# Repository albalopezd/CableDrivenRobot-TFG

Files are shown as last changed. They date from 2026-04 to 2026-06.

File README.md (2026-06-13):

# Robot continuo accionado por cables (2 GDL) — TFG

Trabajo de Fin de Grado. Diseño, construcción y control de un **robot continuo accionado por
cables** (*cable-driven continuum robot*) de 4 segmentos, accionado por 3 tendones, con
2 grados de libertad que posicionan el extremo en el plano XY. El robot se
modela con **cinemática de curvatura constante por tramos (PCC)** y se controla en tiempo real
con **ROS2 Jazzy + ros2_control**, un **Arduino** como intermediario y tres **servos LX-16A**.
Incluye cinemática directa e inversa, visualización en RViz, interfaz gráfica y validación
experimental sobre el robot físico.

<p align="center">
  
  
  WhatsApp Image
</p>

---

## 🎬 Vídeos

| Primera aproximación de movimiento | Demostración IK | Demostración sliders
|:---:|:---:|:---:|
| Primera aproximación de movimiento (https://www.youtube.com/shorts/9lynUKzb-aw) | Demo IK (https://youtu.be/HkvytLLgjOQ) | Demo sliders (https://youtu.be/xODviwTWwIY) |
| Pruebas iniciales de actuación de los cables y respuesta del robot. | Funcionamiento completo: control cinemático. | Funcionamiento por variación longitud de cables manual |

---

## Descripción del proyecto

Un robot continuo no tiene articulaciones rígidas: su estructura se deforma de forma continua.
En este caso, una columna central flexible recorre **4 segmentos** separados por discos, y
**3 cables (tendones)** dispuestos a **0°, +90° y −90°** (triángulo isósceles rectángulo) tiran
de los segmentos para curvar el robot en cualquier dirección del plano.

Al ser una **única sección de curvatura constante**, el robot tiene **2 grados de libertad**:
la **curvatura** (cuánto dobla) y la **orientación del plano de doblez** (hacia dónde dobla).
Esos 2 GDL posicionan el extremo en el plano **XY**. Los 3 tendones son redundantes respecto a
esos 2 GDL: aportan tensión y equilibrio, no una dirección de movimiento adicional. La
coordenada **z no es un grado de libertad independiente**, sino una consecuencia geométrica del
doblez (el extremo se acorta en vertical al curvarse).

El comportamiento se describe con el modelo **PCC (Piecewise Constant Curvature)**, que asume
curvatura constante en cada tramo y permite resolver:

- **Cinemática inversa (IK):** dada una posición objetivo del extremo `(x, y, z)`, calcula
  cuánto debe tirar cada cable.
- **Cinemática directa (FK):** dada la longitud de cada cable, estima la posición del extremo.

### Parámetros del robot

| Parámetro | Valor |
|---|---|
| Número de segmentos | 4 |
| Grados de libertad | 2 (curvatura + orientación del plano de doblez) |
| Separación entre discos | 0,053 m |
| Número de cables (tendones) | 3, a 0°, +90° y −90° (triángulo isósceles rectángulo) |
| Servos | LX-16A — IDs 7, 10 y 4 |

---

## Hardware

**Componentes principales:**

- 3× servos **LX-16A** (Lewansoul) en bus serie semidúplex, cada uno acciona un tendón.
- **Arduino** como pasarela entre el PC y el bus de servos.
- Fuente externa **6 V** (LiPo 2S) para alimentar los servos, con masa común con el Arduino.
- Piezas estructurales impresas en **PLA** (FDM): segmentos separadores, base, poleas de
  tendones y soportes.

**Arquitectura de comunicación (dos capas):**

```
PC  ──USB, 9600 baud──►  Arduino  ──SoftwareSerial, 115200 baud──►  Bus LX-16A (3 servos)
```

El Arduino recibe comandos del PC por el puerto USB (Hardware Serial) y los traduce al protocolo
del bus Lewansoul (SoftwareSerial), además de devolver lecturas de voltaje de los servos.

**Recursos de diseño en el repositorio:**

- [`schematics/`](schematics/) — esquema eléctrico (KiCad).
- [`parts/`](parts/) — piezas mecánicas (FreeCAD, `.FCStd`).
- [`meshes/`](meshes/) — mallas `.STL` para impresión y visualización en RViz.

---

## Arquitectura software (ROS2)

El control se reparte en cuatro paquetes ROS2 dentro de [`ros2_ws/src/`](ros2_ws/src/):

| Paquete | Función |
|---|---|
| `cable_robot_kinematics` | Cinemática PCC (IK/FK) y nodos puente, GUI e interfaz de control. |
| `cable_robot_description` | Modelo URDF (xacro), mallas y configuración de RViz. |
| `cable_robot_hardware` | Plugin de `ros2_control` (`SystemInterface`) que comunica por puerto serie con el Arduino. |
| `cable_robot_bringup` | Fichero de *launch* y configuración de controladores. |

**Nodos principales** (`cable_robot_kinematics`):

- `ik_bridge_cpp` — cinemática inversa: `desired_pose` → comandos de cable.
- `fk_bridge_cpp` — cinemática directa: estado de los cables → `estimated_pose`.
- `cable_bend_bridge_cpp` / `joint_state_combiner_cpp` — convierten el estado de los cables a
  curvatura por segmento para visualizar la deformación en RViz.
- `hardware_controller.py` — control proporcional de velocidad sobre los servos.
- `cable_slider_gui.py` — interfaz Tkinter para mover cada cable y enviar objetivos de IK.
- `data_logger.py` — registro de datos a CSV.

**Flujo de control:**

```
            ┌──────────────┐   cables   ┌────────────┐  serie  ┌─────────┐   ┌─────────┐
desired_pose│  ik_bridge   ├───────────►│ ros2_control├────────►│ Arduino ├──►│ LX-16A  │
   (RViz/   │   (IK PCC)   │            │  + plugin   │         │         │   │ (×3)    │
    GUI)    └──────────────┘            └─────┬───────┘         └─────────┘   └─────────┘
                                              │ /joint_states
                                        ┌─────▼───────┐
                                        │  fk_bridge  │──► estimated_pose ──► RViz / GUI
                                        │   (FK PCC)  │
                                        └─────────────┘
```

**Firmware Arduino** en [`Arduino/main/`](Arduino/main/): sketch principal (`main.ino`) más las
librerías `LX16A`, `TendonRobot` y `PCCkinematics` (que permiten también un modo de control
autónomo sin ROS).

---

## Requisitos

- **Ubuntu** con **ROS2 Jazzy**.
- `ros2_control` y `ros2_controllers` (`sudo apt install ros-jazzy-ros2-control ros-jazzy-ros2-controllers`).
- `xacro` y `colcon`.
- **Arduino IDE** para cargar el firmware.
- *Opcional:* PlotJuggler (`sudo apt install ros-jazzy-plotjuggler-ros`) para visualizar
  señales en tiempo real.

---

## Instalación y compilación

```bash
git clone https://github.com/albalopezd/CableDrivenRobot-TFG.git
cd CableDrivenRobot-TFG/ros2_ws
colcon build
source install/setup.bash
```

Carga el firmware en el Arduino abriendo `Arduino/main/main.ino` en el Arduino IDE y subiéndolo
a la placa.

---

## Ejecución

Con el robot conectado por USB:

```bash
source /opt/ros/jazzy/setup.bash
source ~/CableDrivenRobot-TFG/ros2_ws/install/setup.bash
ros2 launch cable_robot_bringup bringup.launch.py
```

Esto arranca toda la arquitectura con un solo comando: `ros2_control`, `robot_state_publisher`,
**RViz**, los controladores, los puentes de cinemática (IK/FK) y la **GUI** de control.

El puerto serie se puede ajustar con el argumento `serial_port` (por defecto `/dev/ttyACM0`):

```bash
ros2 launch cable_robot_bringup bringup.launch.py serial_port:=/dev/ttyACM1
```

---

## Resultados y validación

Se grabaron tres pruebas experimentales sobre el robot físico (rosbags en
[`ros2_ws/bags/`](ros2_ws/bags/)):

1. **Sliders manuales** — actuación independiente de cada cable.
2. **Control por cinemática inversa** — seguimiento de una secuencia de *waypoints* en el plano XY.
3. **Evaluación de la cinemática directa** — comparación entre posición estimada y deseada.

**Error de posicionamiento en estado estacionario (plano XY):**

| Tipo de objetivo | Error XY |
|---|---|
| Ejes simples (X o Y) | ≈ 0,8 – 1,2 mm |
| Diagonales | ≈ 7 mm |

Los rosbags de las tres pruebas están disponibles en [`ros2_ws/bags/`](ros2_ws/bags/) para
su reproducción y análisis.

---

## Estructura del repositorio

```
CableDrivenRobot-TFG/
├── Arduino/      Firmware del Arduino (sketch + librerías LX16A, TendonRobot, PCCkinematics)
├── ros2_ws/      Workspace ROS2 (4 paquetes) + rosbags
├── parts/        Piezas mecánicas en FreeCAD (.FCStd)
├── meshes/       Mallas .STL para impresión 3D y RViz
├── schematics/   Esquema eléctrico (KiCad)
├── scenes/       Escenas de CoppeliaSim (validación cinemática previa)
└── csv/          Datos de validación cinemática (simulación)
```

---

## Validación previa en CoppeliaSim

Antes de la implementación física, la cinemática se validó en simulación con **CoppeliaSim**.
Las escenas están en [`scenes/`](scenes/) (`kinematic_3d_validation.ttt`,
`kinematic_3d_validation_complete_arm.ttt`) y los datos generados en [`csv/`](csv/), comparando
posición real (simulada) frente a la teórica para cinemática directa e inversa.

---

## Autoría

Trabajo de Fin de Grado — Alba López.

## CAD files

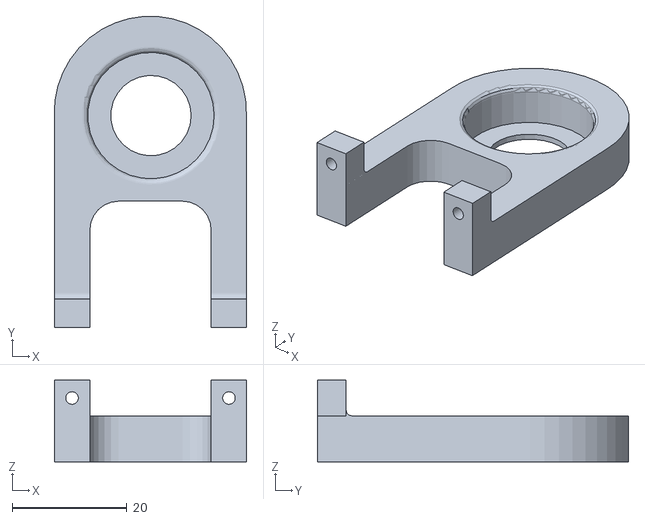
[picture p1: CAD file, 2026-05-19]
meshes/holder.stl
33.5 x 54.2 x 14.2

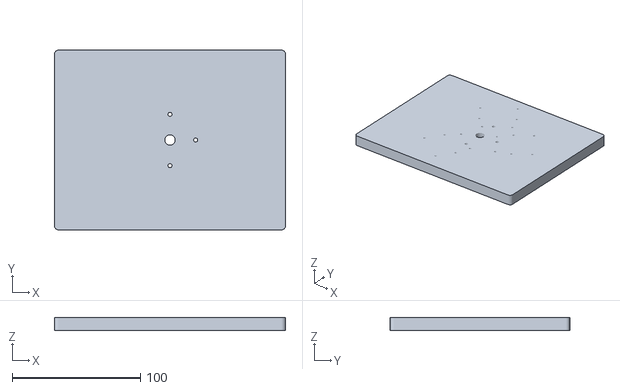
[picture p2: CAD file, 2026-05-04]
ros2_ws/src/cable_robot_description/meshes/base.stl
180.0 x 140.0 x 10.0

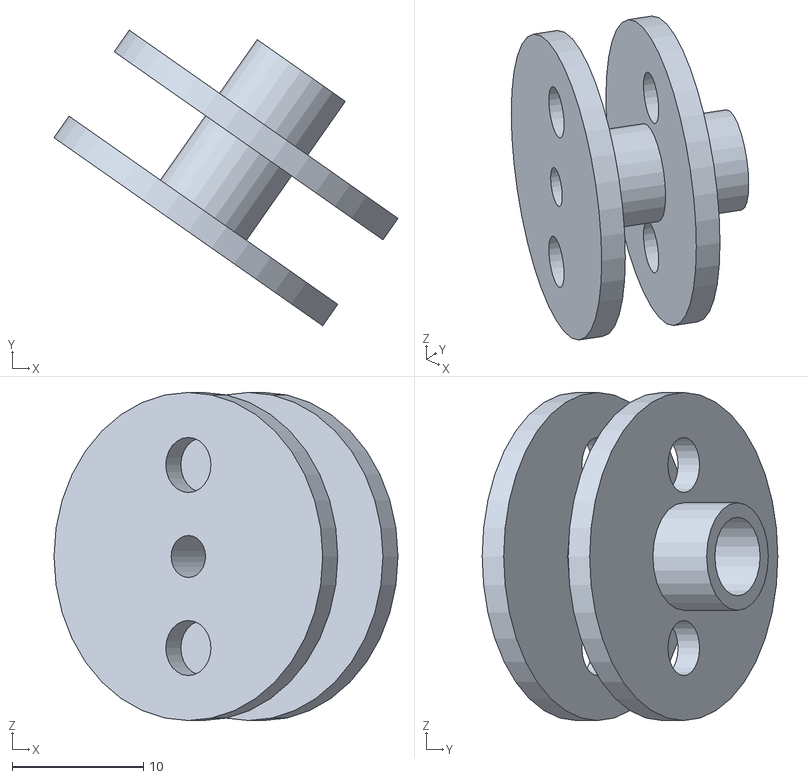
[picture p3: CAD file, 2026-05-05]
meshes/pulley.stl
26.2 x 22.5 x 25.0

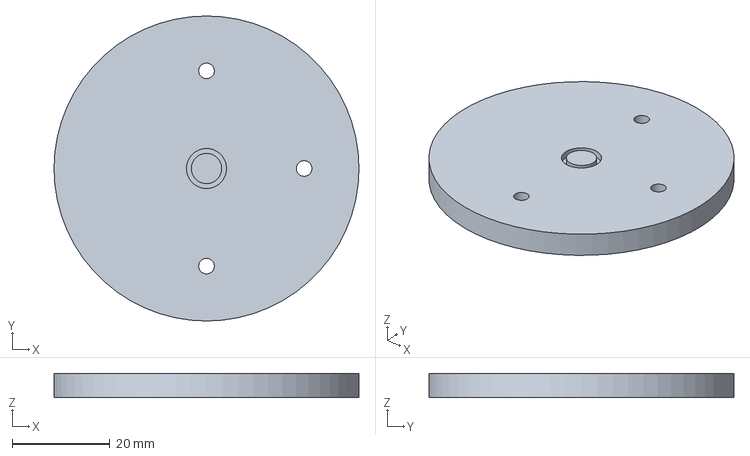
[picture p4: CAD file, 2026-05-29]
parts/segment.FCStd
62.5 x 62.5 x 5.00 mm

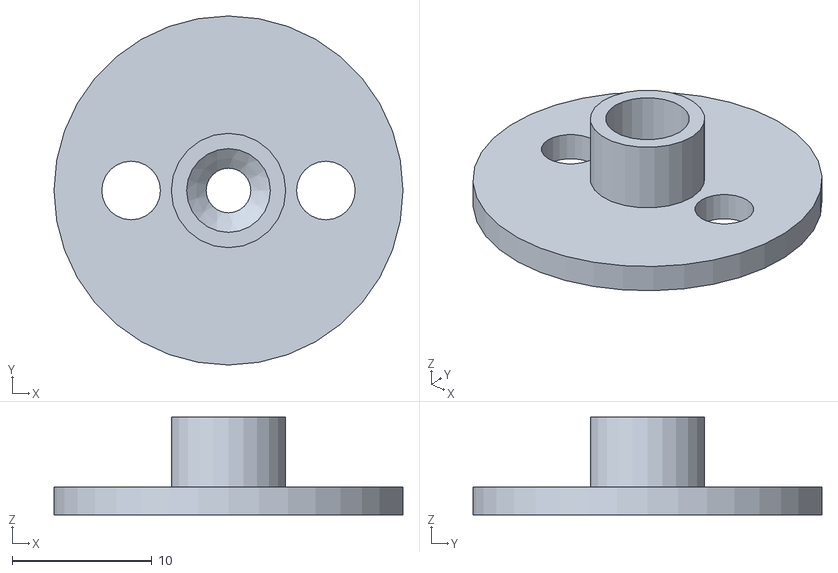
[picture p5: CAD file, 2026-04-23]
ros2_ws/src/cable_robot_description/meshes/pulley_up.stl
25.0 x 25.0 x 7.00

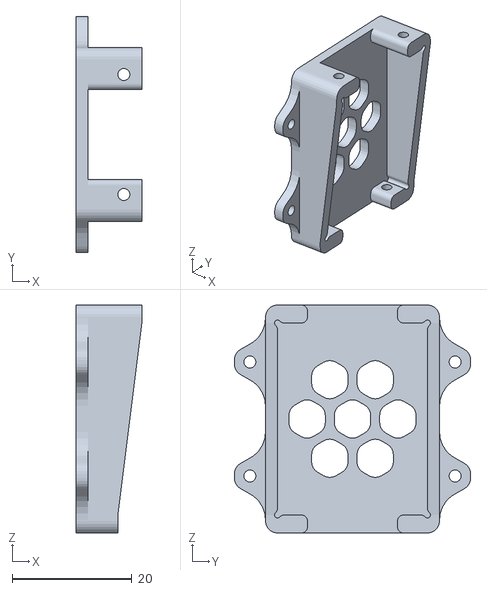
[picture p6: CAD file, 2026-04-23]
ros2_ws/src/cable_robot_description/meshes/servo_bottom_mount.stl
11.0 x 39.4 x 38.0

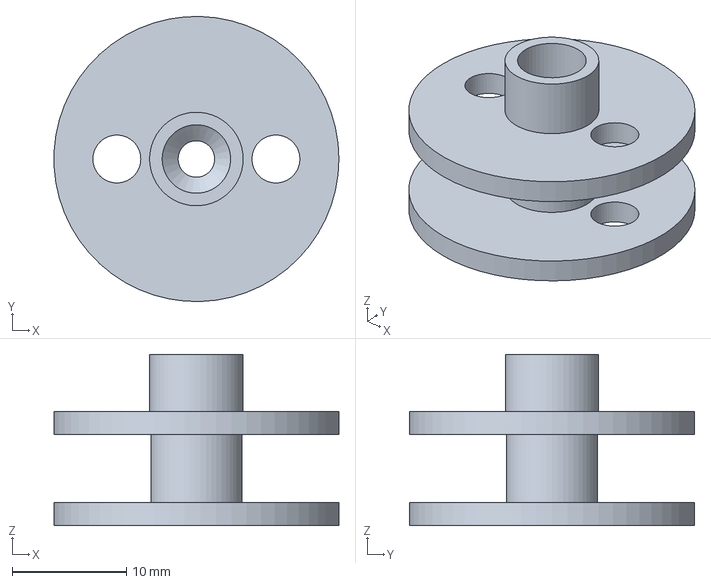
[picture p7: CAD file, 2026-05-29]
parts/pulley.FCStd
25.0 x 25.0 x 15.0 mm

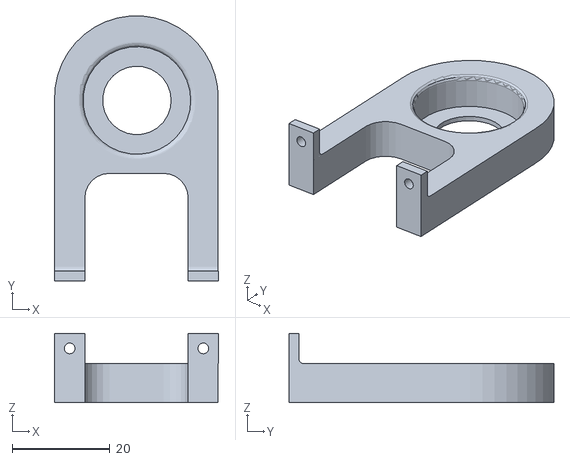
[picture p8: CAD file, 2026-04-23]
ros2_ws/src/cable_robot_description/meshes/holder.stl
33.5 x 54.2 x 14.2

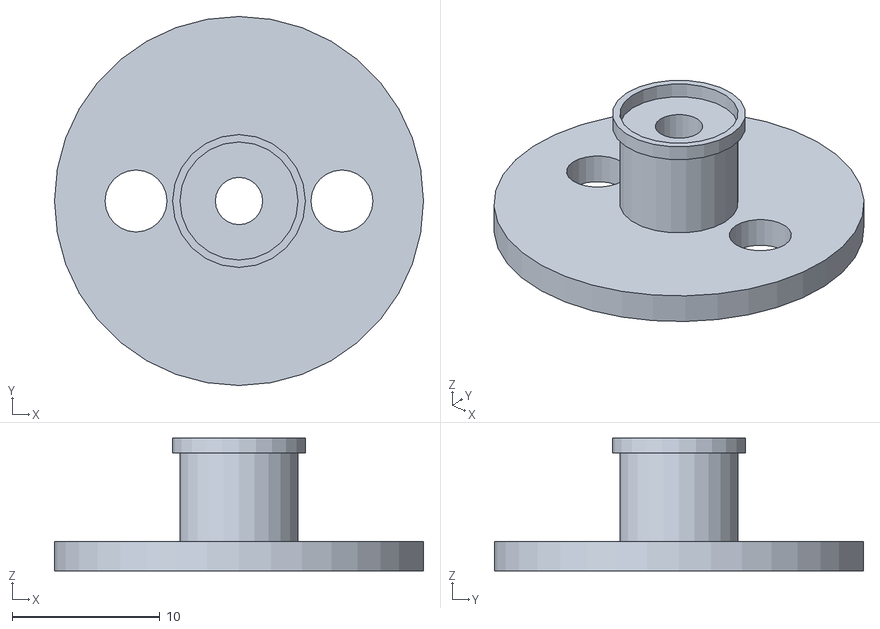
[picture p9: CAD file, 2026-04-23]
ros2_ws/src/cable_robot_description/meshes/pulley_down.stl
25.0 x 25.0 x 9.00

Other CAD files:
parts/holder.FCStd
parts/base.FCStd
ros2_ws/src/cable_robot_description/meshes/segment.stl

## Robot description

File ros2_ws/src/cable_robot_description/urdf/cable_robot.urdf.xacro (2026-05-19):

<?xml version="1.0"?>
<robot name="cable_robot" xmlns:xacro="http://www.ros.org/wiki/xacro">

  <xacro:property name="mesh_dir" value="package://cable_robot_description/meshes"/>
  <xacro:property name="mesh_scale" value="0.001"/>
  <xacro:property name="segment_spacing" value="0.05675"/>
  <xacro:property name="cable_radius_offset" value="0.02"/>
  <xacro:property name="cable_radius" value="0.0012"/>
  <xacro:property name="cable_length" value="0.240"/>
  <xacro:property name="cable_start_z" value="-0.01"/>
  <xacro:property name="cable_travel" value="0.08"/>
  <xacro:property name="base_cable_section_length" value="${segment_spacing - cable_start_z}"/>
  <xacro:property name="deg_to_rad" value="0.017453292519943295"/>
  <xacro:property name="cable_1_angle_deg" value="90.0"/>
  <xacro:property name="cable_2_angle_deg" value="-90.0"/>
  <xacro:property name="cable_3_angle_deg" value="0"/>
  <xacro:property name="cable_1_angle" value="${cable_1_angle_deg * deg_to_rad}"/>
  <xacro:property name="cable_2_angle" value="${cable_2_angle_deg * deg_to_rad}"/>
  <xacro:property name="cable_3_angle" value="${cable_3_angle_deg * deg_to_rad}"/>

  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

  <xacro:macro name="segment_stage" params="segment_name parent bend_x_joint bend_y_joint z">
    <link name="${segment_name}_bend_x_link"/>

    <joint name="${bend_x_joint}" type="revolute">
      <parent link="${parent}"/>
      <child link="${segment_name}_bend_x_link"/>
      <origin xyz="0 0 0" rpy="0 0 0"/>
      <axis xyz="1 0 0"/>
      <limit lower="-1.57" upper="1.57" effort="20.0" velocity="1.0"/>
    </joint>

    <link name="${segment_name}_bend_y_link"/>

    <joint name="${bend_y_joint}" type="revolute">
      <parent link="${segment_name}_bend_x_link"/>
      <child link="${segment_name}_bend_y_link"/>
      <origin xyz="0 0 0" rpy="0 0 0"/>
      <axis xyz="0 1 0"/>
      <limit lower="-1.57" upper="1.57" effort="20.0" velocity="1.0"/>
    </joint>

    <link name="${segment_name}">
      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
    </link>

    <joint name="${segment_name}_placement_joint" type="fixed">
      <parent link="${segment_name}_bend_y_link"/>
      <child link="${segment_name}"/>
      <origin xyz="0 0 ${z}" rpy="0 0 0"/>
    </joint>
  </xacro:macro>

  <xacro:macro name="cable_link" params="name joint_name angle">
    <link name="${name}_anchor_link"/>

    <joint name="${joint_name}" type="prismatic">
      <parent link="${name}_anchor_link"/>
      <child link="${name}"/>
      <origin xyz="0 0 0" rpy="0 0 0"/>
      <axis xyz="0 0 1"/>
      <limit lower="0.0" upper="${cable_travel}" effort="50.0" velocity="0.1"/>
    </joint>

    <link name="${name}">
    </link>

    <joint name="base_to_${name}_anchor" type="fixed">
      <parent link="base_link"/>
      <child link="${name}_anchor_link"/>
      <origin xyz="${cable_radius_offset * cos(angle)} ${cable_radius_offset * sin(angle)} ${cable_start_z}" rpy="0 0 0"/>
    </joint>
  </xacro:macro>

  <xacro:macro name="cable_section" params="name parent angle z_mid length">
    <link name="${name}">
      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
    </link>

    <joint name="${parent}_to_${name}" type="fixed">
      <parent link="${parent}"/>
      <child link="${name}"/>
      <origin xyz="${cable_radius_offset * cos(angle)} ${cable_radius_offset * sin(angle)} 0" rpy="0 0 0"/>
    </joint>
  </xacro:macro>

  <link name="world"/>

  <link name="base_link">
    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
  </link>

  <joint name="world_to_base" type="fixed">
    <parent link="world"/>
    <child link="base_link"/>
  </joint>

  <xacro:segment_stage segment_name="segment_1_link" parent="base_link" bend_x_joint="joint_bend_x" bend_y_joint="joint_bend_y" z="${segment_spacing}"/>
  <xacro:segment_stage segment_name="segment_2_link" parent="segment_1_link" bend_x_joint="joint_bend_x_1" bend_y_joint="joint_bend_y_1" z="${segment_spacing}"/>
  <xacro:segment_stage segment_name="segment_3_link" parent="segment_2_link" bend_x_joint="joint_bend_x_2" bend_y_joint="joint_bend_y_2" z="${segment_spacing}"/>
  <xacro:segment_stage segment_name="segment_4_link" parent="segment_3_link" bend_x_joint="joint_bend_x_3" bend_y_joint="joint_bend_y_3" z="${segment_spacing}"/>

  <xacro:cable_link name="cable_1_link" joint_name="cable_1_joint" angle="${cable_1_angle}"/>
  <xacro:cable_section name="cable_1_base_section" parent="base_link" angle="${cable_1_angle}" z_mid="${(cable_start_z + segment_spacing) / 2.0}" length="${base_cable_section_length}"/>
  <xacro:cable_section name="cable_1_section_1" parent="segment_1_link" angle="${cable_1_angle}" z_mid="${segment_spacing / 2.0}" length="${segment_spacing}"/>
  <xacro:cable_section name="cable_1_section_2" parent="segment_2_link" angle="${cable_1_angle}" z_mid="${segment_spacing / 2.0}" length="${segment_spacing}"/>
  <xacro:cable_section name="cable_1_section_3" parent="segment_3_link" angle="${cable_1_angle}" z_mid="${segment_spacing / 2.0}" length="${segment_spacing}"/>
  <xacro:cable_link name="cable_2_link" joint_name="cable_2_joint" angle="${cable_2_angle}"/>
  <xacro:cable_section name="cable_2_base_section" parent="base_link" angle="${cable_2_angle}" z_mid="${(cable_start_z + segment_spacing) / 2.0}" length="${base_cable_section_length}"/>
  <xacro:cable_section name="cable_2_section_1" parent="segment_1_link" angle="${cable_2_angle}" z_mid="${segment_spacing / 2.0}" length="${segment_spacing}"/>
  <xacro:cable_section name="cable_2_section_2" parent="segment_2_link" angle="${cable_2_angle}" z_mid="${segment_spacing / 2.0}" length="${segment_spacing}"/>
  <xacro:cable_section name="cable_2_section_3" parent="segment_3_link" angle="${cable_2_angle}" z_mid="${segment_spacing / 2.0}" length="${segment_spacing}"/>
  <xacro:cable_link name="cable_3_link" joint_name="cable_3_joint" angle="${cable_3_angle}"/>
  <xacro:cable_section name="cable_3_base_section" parent="base_link" angle="${cable_3_angle}" z_mid="${(cable_start_z + segment_spacing) / 2.0}" length="${base_cable_section_length}"/>
  <xacro:cable_section name="cable_3_section_1" parent="segment_1_link" angle="${cable_3_angle}" z_mid="${segment_spacing / 2.0}" length="${segment_spacing}"/>
  <xacro:cable_section name="cable_3_section_2" parent="segment_2_link" angle="${cable_3_angle}" z_mid="${segment_spacing / 2.0}" length="${segment_spacing}"/>
  <xacro:cable_section name="cable_3_section_3" parent="segment_3_link" angle="${cable_3_angle}" z_mid="${segment_spacing / 2.0}" length="${segment_spacing}"/>

  <ros2_control name="CableRobotHardware" type="system">
    <hardware>
      <plugin>cable_robot_hardware/CableRobotHardware</plugin>
      <param name="port">/dev/ttyACM0</param>
      <param name="baud">9600</param>
      <param name="cable_speed">0.026</param>
    </hardware>

    <joint name="cable_1_joint">
      <command_interface name="velocity"/>
      <state_interface name="position">
        <param name="initial_value">0.0</param>
      </state_interface>
    </joint>

    <joint name="cable_2_joint">
      <command_interface name="velocity"/>
      <state_interface name="position">
        <param name="initial_value">0.0</param>
      </state_interface>
    </joint>

    <joint name="cable_3_joint">
      <command_interface name="velocity"/>
      <state_interface name="position">
        <param name="initial_value">0.0</param>
      </state_interface>
    </joint>
  </ros2_control>
</robot>

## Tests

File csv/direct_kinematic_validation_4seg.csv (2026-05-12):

time | x_real | y_real | z_real | x_theo | y_theo | z_theo | theta_total | error_dist | rho_real | bx | by | b1x | b1y | b2x | b2y | b3x | b3y
0.000000 | -0.000000 | -0.000000 | 0.307363 | 0.000000 | 0.000000 | 0.307388 | 0.000000 | 0.000025 | 0.000000 | 0.000000 | 0.000000 | 0.000000 | 0.000000 | 0.000000 | 0.000000 | 0.000000 | 0.000000
0.050000 | 0.000019 | -0.000019 | 0.307363 | 0.000019 | -0.000019 | 0.307388 | 0.000179 | 0.000025 | 0.000028 | 0.000032 | 0.000032 | 0.000032 | 0.000032 | 0.000032 | 0.000032 | 0.000032 | 0.000032
0.100000 | 0.000078 | -0.000078 | 0.307363 | 0.000078 | -0.000078 | 0.307388 | 0.000714 | 0.000025 | 0.000110 | 0.000126 | 0.000126 | 0.000126 | 0.000126 | 0.000126 | 0.000126 | 0.000126 | 0.000126
0.150000 | 0.000174 | -0.000174 | 0.307363 | 0.000174 | -0.000174 | 0.307388 | 0.001600 | 0.000025 | 0.000246 | 0.000283 | 0.000283 | 0.000283 | 0.000283 | 0.000283 | 0.000283 | 0.000283 | 0.000283
0.200000 | 0.000308 | -0.000308 | 0.307363 | 0.000308 | -0.000308 | 0.307388 | 0.002833 | 0.000025 | 0.000435 | 0.000501 | 0.000501 | 0.000501 | 0.000501 | 0.000501 | 0.000501 | 0.000501 | 0.000501
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

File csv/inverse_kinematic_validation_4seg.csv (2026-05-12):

time | target_x | target_y | target_z | real_x | real_y | real_z | error_dist | theta | phi | dl1 | dl2 | dl3 | l1 | l2 | l3
0.000000 | 0.136600 | -0.136600 | 0.200000 | -0.000000 | -0.000000 | 0.307363 | 0.221011 | 0.000000 | -0.000000 | -0.000000 | 0.000000 | -0.000000 | 0.250000 | 0.250000 | 0.250000
0.050000 | 0.136600 | -0.136600 | 0.200000 | 0.000019 | -0.000019 | 0.307363 | 0.220987 | 0.000179 | -0.000092 | -0.000003 | 0.000003 | -0.000001 | 0.250003 | 0.249997 | 0.250001
0.100000 | 0.136600 | -0.136600 | 0.200000 | 0.000078 | -0.000078 | 0.307363 | 0.220915 | 0.000714 | -0.000365 | -0.000010 | 0.000014 | -0.000004 | 0.250010 | 0.249986 | 0.250004
0.150000 | 0.136600 | -0.136600 | 0.200000 | 0.000174 | -0.000174 | 0.307363 | 0.220796 | 0.001600 | -0.000818 | -0.000023 | 0.000031 | -0.000008 | 0.250023 | 0.249969 | 0.250008
0.200000 | 0.136600 | -0.136600 | 0.200000 | 0.000308 | -0.000308 | 0.307363 | 0.220631 | 0.002832 | -0.001448 | -0.000040 | 0.000055 | -0.000015 | 0.250040 | 0.249945 | 0.250015
0.250000 | 0.136600 | -0.136600 | 0.200000 | 0.000479 | -0.000479 | 0.307362 | 0.220419 | 0.004407 | -0.002253 | -0.000062 | 0.000085 | -0.000023 | 0.250062 | 0.249915 | 0.250023
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

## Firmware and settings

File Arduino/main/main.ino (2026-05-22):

#include <SoftwareSerial.h>
#include "LX16A.h"
#include "PCCkinematics.h"
#include "TendonRobot.h"

SoftwareSerial lx16aSerial(10, 11);
LX16A servos(lx16aSerial);

const uint8_t SERVO_IDS[3] = {10, 4, 7};
TendonRobot robot(
  servos,
  4,
  0.02f,
  0.004f,
  1.5708f,
  -1.5708f,
  0.0f,
  SERVO_IDS,
  1000.0f,
  240.0f
);

String inputBuffer = "";

// Velocidades actuales de los servos
int16_t currentSpeeds[3] = {0, 0, 0};

// Voltajes leídos (mV), -1 si no disponible
int voltages[3] = {-1, -1, -1};

unsigned long lastVinRead = 0;
uint8_t vinIndex = 0;   // qué servo leer en este ciclo (0, 1, 2)

void parseVelocity(const String& line) {
    // Formato: "v:s0,s1,s2"
    int colon = line.indexOf(':');
    if (colon < 0) return;
    String data = line.substring(colon + 1);

    int i1 = data.indexOf(',');
    int i2 = data.indexOf(',', i1 + 1);
    if (i1 < 0 || i2 < 0) return;

    currentSpeeds[0] = (int16_t)data.substring(0, i1).toInt();
    currentSpeeds[1] = (int16_t)data.substring(i1 + 1, i2).toInt();
    currentSpeeds[2] = (int16_t)data.substring(i2 + 1).toInt();

    servos.setMotorSpeed(SERVO_IDS[0], currentSpeeds[0]);
    servos.setMotorSpeed(SERVO_IDS[1], currentSpeeds[1]);
    servos.setMotorSpeed(SERVO_IDS[2], currentSpeeds[2]);
}

void parseAndMove(const String& line) {
    // Formato legado: "x,y,z" para control IK standalone
    int i1 = line.indexOf(',');
    int i2 = line.indexOf(',', i1 + 1);
    if (i1 < 0 || i2 < 0) return;

    float x = line.substring(0, i1).toFloat();
    float y = line.substring(i1 + 1, i2).toFloat();
    float z = line.substring(i2 + 1).toFloat();

    robot.moveTo(x, y, z, 1000);
    Serial.println("OK");
}

void setup() {
    Serial.begin(9600);
    lx16aSerial.begin(115200);
    delay(500);
    Serial.println("Set up done");
}

void loop() {
    // Procesar comandos entrantes
    while (Serial.available()) {
        char c = Serial.read();
        if (c == '\n') {
            if (inputBuffer.startsWith("v:")) {
                parseVelocity(inputBuffer);
            } else {
                parseAndMove(inputBuffer);
            }
            inputBuffer = "";
        } else {
            inputBuffer += c;
        }
    }

    // Leer voltaje de un servo cada 500ms (rotando entre los 3)
    unsigned long now = millis();
    if (now - lastVinRead >= 500) {
        lastVinRead = now;

        int vin = servos.readVin(SERVO_IDS[vinIndex]);
        voltages[vinIndex] = vin;
        vinIndex = (vinIndex + 1) % 3;

        // Cuando hemos leído los 3, enviar todos
        if (vinIndex == 0) {
            Serial.print("w:");
            Serial.print(voltages[0]);
            Serial.print(",");
            Serial.print(voltages[1]);
            Serial.print(",");
            Serial.println(voltages[2]);
        }
    }
}

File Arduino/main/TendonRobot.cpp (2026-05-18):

#include "TendonRobot.h"

TendonRobot::TendonRobot(LX16A& servos, int n_seg, float d_cable,
                           float pulley_radius, float phi_c1, float phi_c2,
                           float phi_c3, uint8_t ids[3],
                           float max_position_servo, float max_angle_servo)
    : servos_(servos),         
      n_seg_(n_seg),
      d_cable_(d_cable),
      pulley_radius_(pulley_radius),
      phi_c1_(phi_c1),
      phi_c2_(phi_c2),
      phi_c3_(phi_c3),
      max_position_servo_(max_position_servo),
      max_angle_servo_(max_angle_servo)
{
    ids_[0] = ids[0];
    ids_[1] = ids[1];
    ids_[2] = ids[2];
}

void TendonRobot::moveTo(float x, float y, float z, uint16_t time_ms)
{
  float theta, phi;
  PCCKinematics::invkinematics(x, y, z, theta, phi);
  
  float c1, c2, c3;
  PCCKinematics::getCablePull(theta * n_seg_, phi, c1, c2, c3, d_cable_, 
                          phi_c1_, phi_c2_, phi_c3_);
  
  servos_.move(ids_[0], cableToServoPos(c1), time_ms);
  servos_.move(ids_[1], cableToServoPos(c2), time_ms);
  servos_.move(ids_[2], cableToServoPos(c3), time_ms);
}

uint16_t TendonRobot::cableToServoPos(float cable_length) {
    float angle_rad = cable_length / pulley_radius_;
    float angle_deg = angle_rad * (180.0f / M_PI);
    int delta = (int)(angle_deg * (max_position_servo_ / max_angle_servo_));
    return (uint16_t)constrain((max_position_servo_ / 2) + delta, 0, max_position_servo_);
}

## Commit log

2026-03-19 New scene with the complete arm
2026-03-23 Inverse kinematic calculation
2026-03-30 Changing folder for csv files
    [direct_kinematic_validation_4seg.csv, inverse_kinematic_validation_4seg.csv]
2026-04-08 Adding the part design
    [complete_arm.FCStd, segment.FCStd, segment_endEffector.FCStd]
2026-04-08 Deleting de FcBack
    [complete_arm.FCStd]
2026-04-13 Adding components of the robot
    [base.FCStd, central_body.FCStd, complete_arm.FCStd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]
2026-04-13 Assembly the arm
    [assembly_arm.FCStd, base.FCStd, base_with_motors.FCStd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]
2026-04-14 Modify the parts
    [Sin nombre.FCStd, assembly_arm.FCStd, base.FCStd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]
2026-04-17 Yooyo part complete
    [yoyo.FCStd]
2026-04-17 Create squeme of pulley
    [yoyo.FCStd]
2026-04-21 Complete assembly servos to base
    [assembly_arm.FCStd, base.FCStd, bearing.FCStd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]
2026-04-23 New folder meshes
    [assembly_arm.FCStd, assembly_base.FCStd, base.FCStd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]
2026-05-04 Migration to ROS2 and visualization RViz
    [base.stl, cable_robot.urdf.xacro, holder.stl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]
2026-05-05 Final parts
    [Sin nombre.FCStd, assembly_arm.FCStd, assembly_base.FCStd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]
2026-05-05 Correct pulley
    [pulley.stl]
2026-05-12 checking for simulation
    [direct_kinematic_validation_4seg.csv, inverse_kinematic_validation_4seg.csv]
2026-05-18 Code to use the Arduino
2026-05-19 Implemented forward kinematics
2026-05-19 Adding the hardware control to the joints
    [cable_robot.urdf.xacro]
2026-05-19 Finishing control
    [controllers.yaml]
2026-05-19 Change meshes
    [base.stl, holder.stl, pulley_down.stl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]
2026-05-21 Move correctly in axis
    [cable_log_20260518_191148.csv, cable_log_20260518_193319.csv, cable_log_20260518_193813.csv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]
2026-05-21 Changing tolerance of servos
    [cable_robot.urdf.xacro]
2026-05-22 Solve ik angle problem
    [lx16a_connection.kicad_sch]
2026-05-22 Added to get the voltage oscilation
2026-05-23 Corrected the z for IK and the theta and estimated d_cable for a coordinate movement
    [controllers.yaml]
2026-05-29 Changing parts pages
    [base.FCStd, bearing.FCStd, cable_log_20260518_191148.csv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]
